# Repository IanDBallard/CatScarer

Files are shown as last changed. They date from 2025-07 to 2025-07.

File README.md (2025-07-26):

# CatScarer

An Arduino Nano-based cat deterrent system using PlatformIO for development. This device uses a PIR motion sensor to detect cats and activates deterrent mechanisms including a PWM fan, buzzer, and RGB LED indicators.

## Project Structure

```text
CatScarer/
├── src/                    # Main source code
│   ├── main.cpp           # Main Arduino sketch (CatScareDevice.ino)
│   ├── PIRSensor.h        # PIR motion sensor class header
│   ├── PIRSensor.cpp      # PIR motion sensor class implementation
│   ├── PWMFan.h           # PWM fan control class header
│   ├── PWMFan.cpp         # PWM fan control class implementation
│   ├── Buzzer.h           # Speaker control class header
│   ├── Buzzer.cpp         # Speaker control class implementation
│   ├── RGBLED.h           # RGB LED control class header
│   ├── RGBLED.cpp         # RGB LED control class implementation
│   ├── IRRemote.h         # IR remote control class header
│   ├── IRRemote.cpp       # IR remote control class implementation
│   ├── DeviceStateMachine.h    # State machine class header
│   └── DeviceStateMachine.cpp  # State machine class implementation
├── Parts/                  # 3D printable enclosure parts
│   ├── Cat Scarer Body.3mf # Main enclosure body
│   └── Cat Scarer Lid.3mf  # Enclosure lid/cover
├── include/               # Additional header files
├── lib/                   # Custom libraries
├── test/                  # Unit tests
├── .pio/                  # PlatformIO build artifacts
│   └── build/
│       └── nano/          # Arduino Nano build output
│           ├── firmware.hex    # Compiled firmware ready for upload
│           ├── firmware.elf    # Debug information
│           └── ...             # Other build files
├── platformio.ini         # PlatformIO configuration
├── .gitignore             # Git ignore rules
└── README.md              # This file
```

## 3D Printable Enclosure

### Available Parts

The project includes 3D printable enclosure parts for a complete, professional-looking cat deterrent system:

- Cat Scarer Body.3mf - Main enclosure housing for electronics
- Cat Scarer Lid.3mf - Removable lid for easy access to components

### Printing Specifications

#### Recommended Settings:

- Printer: Any FDM 3D printer (tested on Bambu Lab X1C)
- Material: PLA+ (recommended) or standard PLA
- Layer Height: 0.2mm (standard quality)
- Infill: 20-30% (adequate strength, reasonable print time)
- Supports: Required - Enable supports for overhanging features
- Bed Temperature: 60°C (PLA)
- Hotend Temperature: 210-220°C (PLA+)

#### Alternative Materials:

- PETG: More durable, higher temperature resistance
- ABS: Higher temperature resistance, requires enclosure
- TPU: Flexible, impact resistant (for outdoor use)

### Assembly Instructions

1. Print both parts using the recommended settings
2. Remove supports carefully using pliers or flush cutters
3. Clean up any stringing or remaining support material
4. Test fit the lid on the body before electronics installation
5. Install electronics into the body cavity
6. Secure lid to complete the assembly

### Enclosure Features

- Compact design - Fits all electronics components
- Ventilation holes - Proper airflow for fan operation
- Cable management - Organized routing for power and sensor cables
- Mounting options - Can be wall-mounted or placed on surface
- Weather resistance - Suitable for indoor/outdoor use (with appropriate material)

### Customization

The 3D models can be modified for:

- Different fan sizes - Adjust cavity dimensions
- Additional sensors - Add mounting points
- Different mounting - Modify base or mounting holes
- Material optimization - Adjust wall thickness for different materials

## Hardware Components

### Required Components

- Arduino Nano (ATmega328P) - Main controller
- PIR Motion Sensor - Detects cat movement
- PWM Fan - Physical deterrent (with P30N06LE MOSFET circuit)
- Buzzer - Audio deterrent (with 2N2222 transistor circuit)
- RGB LED - Status indicator (common cathode)
- Current-limiting resistors - 220Ω-330Ω for RGB LED protection

### Complete Component List

#### Microcontrollers (Choose One)

| MCU | Package | Voltage | Flash | RAM | Notes |
|-----|---|---|---|-----|---|
| Arduino Nano | DIP-28 | 5V | 32KB | 2KB | Primary Target |
| Arduino Uno | DIP-28 | 5V | 32KB | 2KB | Direct replacement |
| Arduino Pro Mini | SMD | 5V | 32KB | 2KB | Smaller footprint |
| ESP32 Dev Board | SMD | 3.3V | 4MB | 520KB | WiFi/Bluetooth |
| ESP8266 NodeMCU | SMD | 3.3V | 4MB | 80KB | WiFi enabled |
| STM32F103C8T6 | SMD | 3.3V | 64KB | 20KB | ARM Cortex-M3 |

#### Power Supply Components

| Component | Specification | Quantity | Notes |
|---|---|---|---|
| 12V Power Supply | 12V, 2A+ | 1 | For fan and buzzer |
| Buck Converter | 12V→5V, 1A+ | 1 | LM2596 or MP2307 |
| 5V Regulator | 7805 or AMS1117 | 1 | Backup 5V source |
| Capacitors | 100µF, 25V | 2 | Power filtering |
| Capacitors | 10µF, 16V | 2 | Decoupling |

#### Transistors & MOSFETs

| Component | Package | Rating | Quantity | Purpose |
|---|---|---|---|---|
| P30N06LE | TO-220 | 30A, 60V | 1 | Fan control |
| 2N2222 | TO-92 | 800mA, 40V | 1 | Buzzer control |
| TIP120 | TO-220 | 5A, 60V | 1 | Fan control (alt) |
| IRF530 | TO-220 | 14A, 100V | 1 | Fan control (alt) |

#### Diodes

| Component | Package | Rating | Quantity | Purpose |
|---|---|---|---|---|
| 1N4007 | DO-41 | 1A, 1000V | 2 | Flyback protection |
| 1N4004 | DO-41 | 1A, 400V | 2 | Flyback protection (alt) |
| 1N4001 | DO-41 | 1A, 50V | 2 | Flyback protection (alt) |

#### Resistors

| Value | Power | Quantity | Purpose |
|---|---|---|---|
| 220Ω | 1/4W | 3 | RGB LED current limiting |
| 330Ω | 1/4W | 3 | RGB LED current limiting (alt) |
| 1kΩ | 1/4W | 1 | Speaker base current limiting |
| 22Ω | 1W+ | 1 | Speaker series resistor (5V operation) |
| 10kΩ | 1/4W | 1 | MOSFET gate pull-down |
| 4.7kΩ | 1/4W | 1 | MOSFET gate pull-down (alt) |

#### Sensors & Actuators

| Component | Specification | Quantity | Notes |
|---|---|---|---|
| PIR Sensor | HC-SR501 | 1 | Motion detection |
| RGB LED | Common Cathode | 1 | Status indicator |
| PWM Fan | 12V, 120mm 4-pin PWM | 1 | Physical deterrent |
| Passive Speaker | 8Ω, 0.2W | 1 | Audio deterrent (requires 22Ω series resistor) |
| IR Receiver | TSOP1838 | 1 | Remote control input |

#### Connectors & Hardware

| Component | Specification | Quantity | Purpose |
|---|---|---|---|
| Breadboard | 830 points | 1 | Prototyping |
| Jumper Wires | Male-Male | 20 | Connections |
| Jumper Wires | Male-Female | 10 | Sensor connections |
| Power Jack | 2.1mm DC | 1 | 12V input |
| USB Cable | Type B | 1 | Programming |

### MCU Compatibility Notes

#### Arduino Nano (Primary)

- Voltage: 5V operation
- PWM Pins: 3, 5, 6, 9, 10, 11
- Digital Pins: All pins available
- Memory: Sufficient for all features

#### ESP32/ESP8266 Compatibility

- Voltage: 3.3V operation (requires level shifting)
- PWM: Software PWM on any pin
- WiFi: Built-in connectivity for remote monitoring
- Memory: Abundant for advanced features
- Pin Changes: Update pin definitions in `src/main.cpp`

#### STM32 Compatibility

- Voltage: 3.3V operation
- PWM: Hardware PWM on specific pins
- Performance: Higher clock speed, more memory
- Development: Requires STM32duino framework

### Power Supply Considerations

#### 12V Power Supply Requirements

- Minimum Current: 2A for reliable operation
- Recommended: 3A for headroom
- Voltage Stability: ±5% tolerance
- Protection: Overcurrent and short-circuit protection

#### Buck Converter Selection

- Input: 12V from power supply
- Output: 5V for Arduino, PIR Sensor, RGB LED, and Speaker (via series resistor)
- Current: 1A minimum (Arduino + sensors)
- Efficiency: 85%+ for heat management
- Popular Modules: LM2596, MP2307, XL6009

#### Power Distribution

```text
12V Power Supply
    ├── Buck Converter (12V→5V)
    │   ├── Arduino Nano (5V)
    │   ├── PIR Sensor (5V)
    │   ├── IR Receiver (5V)
    │   ├── RGB LED (5V via 220Ω resistors)
    │   └── Speaker (5V via 22Ω series resistor)
    │
    └── Fan (12V via P30N06LE MOSFET)
```

Power Requirements:

- Fan: 12V directly from power supply
- Speaker: 5V from buck converter (via 22Ω series resistor)
- Arduino & Sensors: 5V from buck converter
- RGB LED: 5V from buck converter (via current-limiting resistors)

#### Alternative Power Solutions

- USB Power: 5V directly (fan needs separate 12V)
- Battery: 12V lead-acid or LiPo with buck converter
- Solar: 12V solar panel with charge controller

### Pin Connections

| Component | Pin | Description |
|---|-----|---|
| PIR Sensor | D2 | Motion detection input |
| Fan PWM | D9 | PWM fan speed control (via P30N06LE MOSFET) |
| Speaker | D3 | Audio output control (via 2N2222 transistor) |
| RGB LED Red | D5 | Red LED control (PWM - variable brightness) |
| RGB LED Green | D6 | Green LED control (PWM - variable brightness) |
| RGB LED Blue | D8 | Blue LED control (Digital - on/off only) |
| IR Receiver | D4 | TSOP1838 IR receiver for remote control |

## Hardware Circuit Diagrams

### Power Distribution Circuit

```text
12V Power Supply (+) ── Buck Converter Input (+)
12V Power Supply (-) ── Buck Converter Input (-) ── GND
Buck Converter Output (+) ── Arduino 5V Pin
Buck Converter Output (-) ── Arduino GND Pin ── GND
```

### Fan Control Circuit (P30N06LE MOSFET)

```text
12V Power Supply (+) ── Fan (Pin 2: +12V Power, Yellow/Red wire)
Fan (Pin 1: Ground, Black wire) ── P30N06LE Drain (Pin 2)
P30N06LE Source (Pin 3) ── GND
Arduino D9 ── P30N06LE Gate (Pin 1) ── 10kΩ Resistor ── GND
                                            (Pull-down resistor for gate)
Flyback Diode (1N4007) across Fan: Cathode to Fan(+), Anode to Fan(-)
```

Fan Wire Colors (4-pin PWM):

- Black: Ground (Pin 1)
- Yellow/Red: +12V Power (Pin 2)
- Blue: PWM Control (Pin 3) - Not used in this circuit
- Green/Yellow: Sense (Pin 4) - Not used in this circuit

### Speaker Circuit (2N2222 Transistor)

```text
Buck Converter 5V Output (+) ── 22Ω Series Resistor (1W+) ── Speaker (+)
Speaker (-) ── 2N2222 Collector
2N2222 Emitter ── GND
Arduino D3 ── 1kΩ Resistor ── 2N2222 Base
Flyback Diode (1N4007) across Speaker: Cathode to Speaker(+), Anode to Speaker(-)
```

Important Notes:

- 5V Power: Supplied by buck converter, not direct Arduino 5V
- Series Resistor: 22Ω, 1W+ required to limit current for 8Ω speaker
- Transistor: 2N2222 switches speaker to ground when Arduino pin is HIGH

### RGB LED Circuit

```text
Buck Converter 5V Output (+) ── 220Ω Resistor ── RGB LED Red Anode
Buck Converter 5V Output (+) ── 220Ω Resistor ── RGB LED Green Anode
Buck Converter 5V Output (+) ── 220Ω Resistor ── RGB LED Blue Anode
RGB LED Common Cathode ── GND
Arduino D5 ── RGB LED Red Anode (via 220Ω resistor)
Arduino D6 ── RGB LED Green Anode (via 220Ω resistor)
Arduino D8 ── RGB LED Blue Anode (via 220Ω resistor)
```

### PIR Sensor Circuit

```text
Buck Converter 5V Output (+) ── PIR Sensor VCC
PIR Sensor GND ── GND
PIR Sensor OUT ── Arduino D2
```

### IR Receiver Circuit

```text
Buck Converter 5V Output (+) ── IR Receiver VCC
IR Receiver GND ── GND
IR Receiver OUT ── Arduino D4
```

### Complete Wiring Diagram

```text
12V Power Supply
    │
    ├── Buck Converter (12V→5V)
    │   ├── Arduino Nano (5V, GND)
    │   ├── PIR Sensor (5V, GND, D2)
    │   ├── IR Receiver (5V, GND, D4)
    │   ├── RGB LED (5V via 220Ω resistors, D5/D6/D8)
    │   └── Speaker Circuit (5V via 22Ω resistor, D3)
    │
    └── Fan Circuit (12V, D9)
        └── P30N06LE MOSFET (D9 → Gate, Fan → Drain, Source → GND)
```

Ground Connections:

- All GND connections must be connected to a single common ground rail
- Buck converter output GND connects to Arduino GND
- All component GND connections connect to this common ground

## Features

### Motion Detection

- PIR sensor continuously monitors for movement
- 45-second warm-up period to establish baseline readings
- Configurable sensitivity and detection range
- Encapsulated warm-up logic within PIRSensor class

### Deterrent Mechanisms

- PWM Fan: Variable speed control for physical deterrent
- Buzzer: Audio deterrent with transistor amplification and siren mode
- RGB LED: Visual status indication
  - Blue flickering: PIR sensor warming up
  - Green solid: Ready/Standby mode
  - Red solid: Active deterrent mode
  - Yellow solid: Inactive mode (device disabled)

### Behavior

- Initialization: 45-second PIR warm-up with blue LED flickering
- Activation: Triggers when motion is detected (after warm-up)
- Duration: Configurable activation time (default: 5 seconds)
- Auto-reset: Returns to standby after activation period
- Continuous monitoring: Refreshes timer if motion continues
- Remote Control: IR remote power toggle to enter/exit inactive mode
- Inactive Mode: Device ignores PIR input when disabled via remote

### Remote Control Operation

The device supports IR remote control using a TSOP1838 receiver and Elegoo-compatible remote:

- Power Toggle: Press power button to toggle between active and inactive modes
- State Transitions: Power toggle works from any state (WARMUP, STANDBY, ACTIVE)
- Inactive Mode: When inactive, device ignores all PIR motion detection
- Visual Feedback: Yellow LED indicates inactive state
- Testing: Send 'P' via serial monitor to simulate power toggle during development

### State Logic

The device operates using a state machine with four distinct states:

```mermaid
WARMUP → STANDBY → ACTIVE
   ↑         ↑         ↑
   └─────────┴─────────┘
        Power Toggle
           ↓
        INACTIVE
           ↑
        Power Toggle
```

- WARMUP: PIR sensor initializing (45 seconds), blue LED flickers
- STANDBY: Ready for motion detection, green LED solid
- ACTIVE: Deterrent active, red LED solid, fan and buzzer running
- INACTIVE: Device disabled, yellow LED solid, ignores PIR input

## Setup

### Prerequisites

1. Install [PlatformIO Core](https://platformio.org/install/cli)
2. Install [Git](https://git-scm.com/)

### Installation

1. Clone this repository:

   ```bash
   git clone <your-repo-url>
   cd CatScarer
   ```

2. Install dependencies:

   ```bash
   pio lib install
   ```

## Usage

### Building

Build for Arduino Nano (default):

```bash
pio run
```

Build for Arduino Nano (explicit):

```bash
pio run -e nano
```

Build for other boards:

```bash
pio run -e uno
pio run -e esp32dev
```

### Uploading

Upload to Arduino Nano (default):

```bash
pio run -t upload
```

Upload to Arduino Nano (explicit):

```bash
pio run -e nano -t upload
```

### Monitoring

Monitor serial output for debugging:

```bash
pio device monitor
```

### Testing

Run all tests:

```bash
pio test
```

## Configuration

### Behavior Parameters

Edit `src/main.cpp` to customize:

```cpp
// Device behavior parameters
const unsigned long ACTIVATION_DURATION_MS = 5000; // Activation duration in milliseconds
const int FAN_SPEED_ACTIVATED = 255; // Fan speed when activated (0-255)

// State machine enum (for reference)
enum DeviceState {
    WARMUP,    // PIR sensor is warming up
    STANDBY,   // Ready for motion detection
    ACTIVE,    // Deterrent is active
    INACTIVE   // Device disabled, ignoring PIR input
};
```

### PIR Sensor Configuration

Edit `src/PIRSensor.cpp` to customize warm-up time:

```cpp
// In constructor - change warm-up duration (default: 45 seconds)
_warmUpDuration(45000) // 45 seconds in milliseconds

// The PIRSensor class includes an update() method that should be called
// in the main loop() for proper state management
```

### Pin Assignments

Modify pin definitions in `src/main.cpp`:

```cpp
const int PIR_PIN = 2;        // PIR sensor pin
const int FAN_PWM_PIN = 9;    // Fan PWM control pin
const int BUZZER_PIN = 3;     // Buzzer control pin
const int LED_RED_PIN = 5;    // RGB LED red pin (PWM)
const int LED_GREEN_PIN = 6;  // RGB LED green pin (PWM)
const int LED_BLUE_PIN = 8;   // RGB LED blue pin (Digital only)
const int IR_RECEIVER_PIN = 4; // IR receiver pin
```

## Hardware Circuit

### Fan Control Circuit Details (P30N06LE MOSFET)

```text
Arduino D9 ──┬── 10kΩ Resistor ── GND
            │
            └── P30N06LE Gate
                    ↓
                P30N06LE Source ── GND
                    ↓
                P30N06LE Drain ── Fan (+)
                          ↓
                      Fan (-) ── GND
                          │
                      Flyback Diode (1N4007)
```

Component Details:

- P30N06LE: N-channel MOSFET (30A, 60V)
- 10kΩ Resistor: Pull-down resistor for gate
- Fan: 12V or 5V PC fan (4-pin PWM fan supported)
- 1N4007 Diode: Flyback protection diode (cathode to fan +, anode to fan -)

### Buzzer Circuit (2N2222 Transistor)

```text
Arduino D3 ──┬── 1kΩ Resistor ── 2N2222 Base
            │
            └── 2N2222 Emitter ── GND
                    ↓
                2N2222 Collector ── Buzzer (+)
                          ↓
                      Buzzer (-) ── GND
                          │
                      Flyback Diode (1N4007)
```

Component Details:

- 2N2222: NPN transistor for current amplification
- 1kΩ Resistor: Base current limiting resistor
- Buzzer: 5V or 12V piezo buzzer
- 1N4007 Diode: Flyback protection diode (cathode to buzzer +, anode to buzzer -)

### RGB LED Circuit (Common Cathode)

```text
Arduino D5 ── 220Ω Resistor ── LED Red Anode (PWM - variable brightness)
Arduino D6 ── 220Ω Resistor ── LED Green Anode (PWM - variable brightness)
Arduino D8 ── 220Ω Resistor ── LED Blue Anode (Digital - on/off only)
Arduino D4 ── TSOP1838 IR Receiver (Signal)
TSOP1838 VCC ── 5V
TSOP1838 GND ── GND
                    │
                LED Common Cathode ── GND
```

Component Details:

- 220Ω Resistors: Current-limiting resistors (220Ω-330Ω acceptable)
- RGB LED: Common cathode type (longest pin = cathode)
- Pin Configuration: Red, Green, Blue anodes + Common cathode
- PWM Control: Red and Green channels support variable brightness (0-255)
- Digital Control: Blue channel is on/off only due to non-PWM pin limitation

### Complete Wiring Diagram

```text
Arduino Nano
┌─────────────────────────────────────────────────────────┐
│                                                         │
│  D2 ────────────────── PIR Sensor OUT                   │
│                                                         │
│  D3 ── 1kΩ ── 2N2222 Base                              │
│             2N2222 Emitter ── GND                       │
│             2N2222 Collector ── Buzzer (+)              │
│                                    Buzzer (-) ── GND    │
│                                    │                    │
│                                    └─ 1N4007 Diode ─────┘
│                                                         │
│  D5 ── 220Ω ── RGB LED Red Anode                        │
│  D6 ── 220Ω ── RGB LED Green Anode                      │
│  D8 ── 220Ω ── RGB LED Blue Anode                       │
│                                    RGB LED Cathode ── GND│
│                                                         │
│  D9 ── 10kΩ ── P30N06LE Gate                            │
│              P30N06LE Source ── GND                     │
│              P30N06LE Drain ── Fan (+)                  │
│                                    Fan (-) ── GND       │
│                                    │                    │
│                                    └─ 1N4007 Diode ─────┘
│                                                         │
│  VIN ── 12V Power Supply (for fan)                      │
│  5V ── 5V Power Supply (for Arduino)                    │
│  GND ── Common Ground                                   │
└─────────────────────────────────────────────────────────┘
```

### Power Supply Requirements

- Arduino Nano: 5V via USB or VIN pin
- Fan: 12V (or 5V depending on fan type)
- Buzzer: 5V or 12V (check buzzer specifications)
- RGB LED: 5V (regulated by resistors)
- PIR Sensor: 5V

### Component Specifications

| Component | Specification | Notes |
|---|---|---|
| P30N06LE | 30A, 60V N-MOSFET | TO-220 package |
| 2N2222 | 800mA, 40V NPN | TO-92 package |
| RGB LED | Common Cathode | 20mA per color |
| Resistors | 220Ω-330Ω | 1/4W or higher |
| Fan | 12V PWM | 4-pin connector supported |
| Buzzer | 5V/12V Piezo | Check voltage rating |
| 1N4007 | 1A, 1000V Diode | Flyback protection (2x) |

## Supported Boards

- Arduino Nano (Primary target - ATmega328P)
- Arduino Uno
- ESP32 Dev Board
- ESP8266 NodeMCU

## Development

### Adding Libraries

Add libraries to `platformio.ini`:

```ini
lib_deps =
    library_name
    another_library
```

Or install via command line:

```bash
pio lib install "library_name"
```

### Software Architecture

The project follows object-oriented design principles with proper encapsulation and separation of concerns:

#### Component Classes

- `PIRSensor`: Motion detection interface with built-in warm-up logic and state management
- `PWMFan`: Fan speed control with PWM support
- `Buzzer`: Audio output control with non-blocking siren mode
- `RGBLED`: Color LED control with PWM support for red/green channels
- `IRRemote`: IR remote control interface with debouncing and power toggle support

#### State Management

- `DeviceStateMachine`: Centralized state machine managing device behavior and transitions
  - WARMUP: PIR sensor initialization (45 seconds)
  - STANDBY: Ready for motion detection
  - ACTIVE: Deterrents active
  - INACTIVE: Device disabled via remote control

#### Main Program Structure

```cpp
void loop() {
  // Update all component states
  myPIR.update();
  myBuzzer.update();
  myIRRemote.update();

  // Update state machine
  stateMachine.update();
}
```

#### Design Benefits

- Encapsulation: Each class has clear responsibilities
- Maintainability: Changes to state logic only affect DeviceStateMachine
- Testability: Individual classes can be unit tested
- Reusability: Methods can be used by other parts of the code
- No Global State: All state is properly encapsulated

#### Recent Refactoring Improvements (V1.4.2)

- Eliminated Stranded Methods: Moved `checkIRPowerToggle()` to `IRRemote` class
- State Machine Encapsulation: Created `DeviceStateMachine` class for all state logic
- Cleaner Main Loop: Simplified main.cpp to focus on orchestration
- Better Code Organization: Proper separation of concerns
- Enhanced Maintainability: Easier to modify and extend functionality

### Project Configuration

Edit `platformio.ini` to customize:

- Board settings
- Build flags
- Upload settings
- Monitor configuration

## Troubleshooting

### Common Issues

1. Upload fails: Check USB connection and COM port
2. PIR not detecting: Verify wiring and wait for 45-second warm-up
3. Fan not spinning: Check MOSFET circuit and PWM pin
4. Buzzer not working: Verify transistor circuit and pin connections
5. LED dim or wrong colors: Check resistor values (should be 220Ω-330Ω)

### LED Status Indicators

- Blue flickering: PIR sensor warming up (45 seconds)
- Green solid: Ready for motion detection (STANDBY state)
- Red solid: Motion detected, deterrents active (ACTIVE state)
- Yellow solid: Device disabled via remote control (INACTIVE state)

### Debug Output

Enable serial monitoring to see debug messages:

```bash
pio device monitor
```

Expected output:

```text
Cat Scare Device Starting...
Testing LED colors...
Testing RED pin (D5)...
Testing GREEN pin (D6)...
Testing BLUE pin (D8)...
ALL LEDS OFF
PIR sensor warming up...
Device ready.
Device State Machine initialized.
Warm-up complete. Entering standby mode.
Motion detected! Activating deterrent...
Setting LED to RED (255,0,0)
Deactivating deterrent...
Setting LED to GREEN (0,255,0)
IR Power toggle: Entering inactive mode.
IR Power toggle: Exiting inactive mode, entering standby.
```

## Contributing

1. Fork the repository
2. Create a feature branch
3. Make your changes
4. Add tests if applicable
5. Submit a pull request

## License

This project is licensed under the GNU General Public License v3.0 - see the [LICENSE](LICENSE) file for details.

### License Summary

- License: GNU General Public License v3.0
- Permissions: Commercial use, modification, distribution, patent use, private use
- Conditions: License and copyright notice must be included, state changes must be disclosed, source code must be made available
- Limitations: No warranty, no liability

For more information about the GPL v3 license, visit: https://www.gnu.org/licenses/gpl-3.0.html

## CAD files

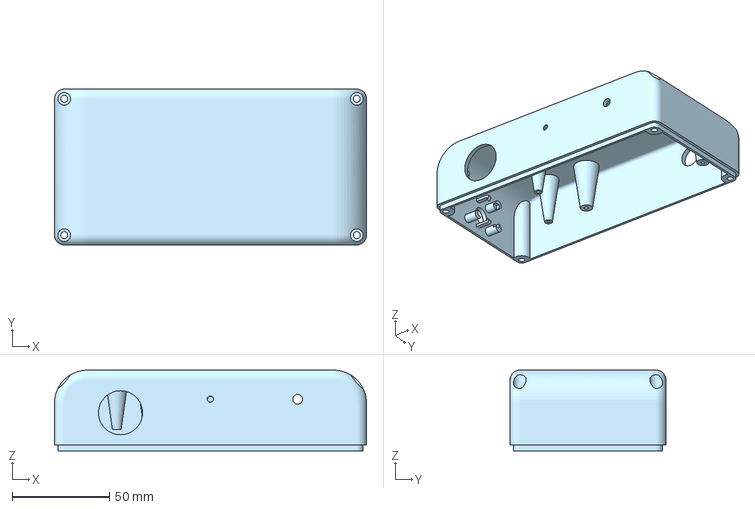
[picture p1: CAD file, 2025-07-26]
Parts/Cat Scarer Lid with IR Receiver.3mf
160.2 x 80.0 x 41.5 mm

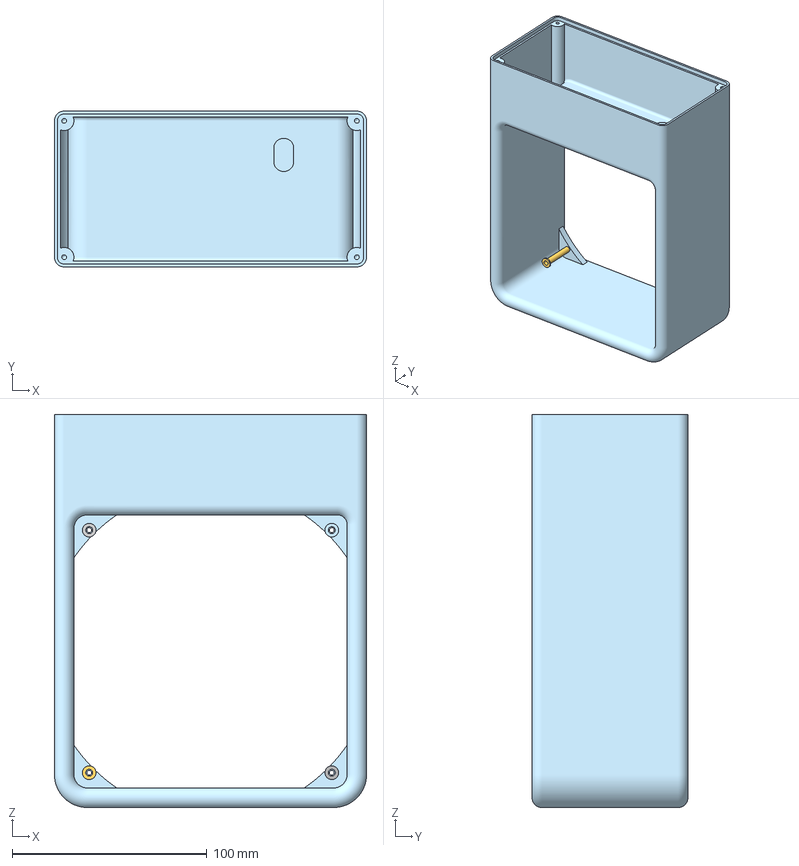
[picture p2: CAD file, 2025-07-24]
Parts/Cat Scarer Body.3mf
160.2 x 80.0 x 201.7 mm

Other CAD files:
Parts/Cat Scarer Lid.3mf

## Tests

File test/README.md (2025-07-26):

# CatScarer Test Suite

This directory contains comprehensive Unity test suites for all CatScarer classes to ensure code quality and reliability.

## Test Coverage

### PIRSensor Tests (`test_PIRSensor.cpp`)

- ✅ Constructor and pin assignment
- ✅ Initialization and warm-up period (45 seconds)
- ✅ Motion detection during and after warm-up
- ✅ State management and transitions
- ✅ Pin getter functionality

### Buzzer Tests (`test_Buzzer.cpp`)

- ✅ Constructor and pin assignment
- ✅ Basic turnOn/turnOff functionality
- ✅ Siren mode activation and deactivation
- ✅ Non-blocking tone switching (800Hz ↔ 400Hz)
- ✅ Timing and duration management
- ✅ State tracking and queries

### IRRemote Tests (`test_IRRemote.cpp`)

- ✅ Constructor and pin assignment
- ✅ IR signal detection and command parsing
- ✅ Power toggle functionality
- ✅ Debouncing (200ms delay)
- ✅ Serial simulation for testing
- ✅ State management and clearing

### DeviceStateMachine Tests (`test_DeviceStateMachine.cpp`)

- ✅ Constructor and initialization
- ✅ All state transitions (WARMUP → STANDBY → ACTIVE → INACTIVE)
- ✅ IR power toggle integration
- ✅ Motion detection integration
- ✅ Duration management and timeouts
- ✅ Component coordination (LED, Fan, Buzzer)
- ✅ State name resolution

## Running Tests

### Run All Tests

```bash
pio test -e native
```

### Run Individual Test Suites

```bash
# PIRSensor tests only
pio test -e native -f test_PIRSensor

# Buzzer tests only
pio test -e native -f test_Buzzer

# IRRemote tests only
pio test -e native -f test_IRRemote

# DeviceStateMachine tests only
pio test -e native -f test_DeviceStateMachine
```

### Run Specific Test Functions

```bash
# Run specific test function
pio test -e native -f test_PIRSensor_constructor
pio test -e native -f test_Buzzer_siren_update_tone_switching
pio test -e native -f test_DeviceStateMachine_standby_to_active
```

## Test Architecture

### Mock System

- **Arduino Functions**: Mocked `millis()`, `tone()`, `noTone()`, `Serial`
- **Hardware Abstraction**: Mock classes for all components
- **Time Control**: Controlled timing for testing time-based behavior

### Test Fixtures

Each test suite includes:

- `setUp()`: Initialize test objects and reset mocks
- `tearDown()`: Clean up allocated memory
- Mock objects for isolated testing

### Mock Classes

- `MockPIRSensor`: Simulates PIR sensor behavior
- `MockPWMFan`: Tracks fan state and speed
- `MockBuzzer`: Simulates buzzer and siren behavior
- `MockRGBLED`: Captures LED color commands
- `MockIRRemote`: Simulates IR remote interactions

## Test Categories

### Unit Tests

- Individual method functionality
- Constructor and initialization
- State management
- Error handling

### Integration Tests

- Component interaction
- State machine transitions
- Timing and coordination
- End-to-end workflows

### Behavioral Tests

- Real-world scenarios
- Edge cases and timing
- State transitions
- User interactions

## Expected Test Results

### All Tests Should Pass

```bash
=== Running PIRSensor Tests ===
test_PIRSensor_constructor:PASS
test_PIRSensor_begin:PASS
test_PIRSensor_warmup_period:PASS
...

=== Running Buzzer Tests ===
test_Buzzer_constructor:PASS
test_Buzzer_startSiren:PASS
test_Buzzer_siren_update_tone_switching:PASS
...

=== Running IRRemote Tests ===
test_IRRemote_constructor:PASS
test_IRRemote_update_power_command:PASS
test_IRRemote_debouncing:PASS
...

=== Running DeviceStateMachine Tests ===
test_DeviceStateMachine_constructor:PASS
test_DeviceStateMachine_standby_to_active:PASS
test_DeviceStateMachine_active_duration:PASS
...

=== All Tests Complete ===
```

## Adding New Tests

### For New Classes

1. Create `test_ClassName.cpp`
2. Include Unity and class header
3. Add mock functions as needed
4. Create test functions with descriptive names
5. Add to `run_all_tests.cpp`

### For New Methods

1. Add test function to existing test file
2. Test normal operation
3. Test edge cases
4. Test error conditions
5. Update test runner

### Test Naming Convention

- `test_ClassName_methodName_behavior()`
- `test_ClassName_methodName_edgeCase()`
- `test_ClassName_methodName_errorCondition()`

## Continuous Integration

These tests can be integrated into CI/CD pipelines to:
- ✅ Ensure code quality
- ✅ Prevent regressions
- ✅ Validate refactoring
- ✅ Document expected behavior
- ✅ Enable safe development

## Troubleshooting

### Test Failures

1. Check mock setup in `setUp()`
2. Verify timing in time-based tests
3. Ensure proper state initialization
4. Check for memory leaks in `tearDown()`

### Compilation Issues

1. Verify Unity library is installed
2. Check include paths
3. Ensure mock functions are defined
4. Validate C++ standard compatibility

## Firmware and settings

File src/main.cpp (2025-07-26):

// CatScareDevice.ino

// Include our custom classes
#include "PIRSensor.h"
#include "PWMFan.h"
#include "Buzzer.h"
#include "RGBLED.h"
#include "IRRemote.h"
#include "DeviceStateMachine.h"

// --- Pin Definitions ---
// Connect PIR Sensor OUT pin to this digital input pin
const int PIR_PIN = 2; // Using D2 for PIR sensor

// Connect Fan PWM input wire (usually yellow) to this PWM pin
// The fan's power is controlled by the TIP120 transistor circuit.
const int FAN_PWM_PIN = 9; // Using D9 for PWM fan control (must be a PWM pin)

// Connect Buzzer signal pin (via 2N2222 transistor circuit) to this digital output pin
const int BUZZER_PIN = 3; // Using D3 for buzzer control

// RGB LED Pins (connect via current-limiting resistors)
// Red and Green pins are PWM-capable for variable brightness
// Blue pin is digital only (on/off)
const int LED_RED_PIN   = 5; // Using D5 for Red LED (PWM)
const int LED_GREEN_PIN = 6; // Using D6 for Green LED (PWM)
const int LED_BLUE_PIN  = 8; // Using D8 for Blue LED (digital only)

// IR Receiver Pin (TSOP1838)
const int IR_RECEIVER_PIN = 4; // Using D4 for IR receiver

// --- Device Behavior Parameters ---
const unsigned long ACTIVATION_DURATION_MS = 5000; // How long the fan/buzzer stays on (5 seconds)
const int FAN_SPEED_ACTIVATED = 255; // Fan speed when activated (0-255, 255 is full speed)

// --- Object Instantiation ---
// Create instances of our component classes
PIRSensor myPIR(PIR_PIN);
PWMFan myFan(FAN_PWM_PIN);
Buzzer myBuzzer(BUZZER_PIN);
RGBLED myLED(LED_RED_PIN, LED_GREEN_PIN, LED_BLUE_PIN);
IRRemote myIRRemote(IR_RECEIVER_PIN);

// Create state machine instance
DeviceStateMachine stateMachine(myPIR, myFan, myBuzzer, myLED, myIRRemote, 
                                ACTIVATION_DURATION_MS, FAN_SPEED_ACTIVATED);

void setup() {
  // Initialize Serial communication for debugging
  Serial.begin(9600);
  Serial.println("Cat Scare Device Starting...");

  // Initialize all components
  myPIR.begin();
  myFan.begin();
  myBuzzer.begin();
  myLED.begin();
  myIRRemote.begin();
  stateMachine.begin();

  // LED Test - cycle through colors
  Serial.println("Testing LED colors...");
  Serial.println("NOTE: If LED is dim, check resistor value (should be 220-330Ω)");
  
  // Test each pin individually to identify connections
  Serial.println("Testing RED pin (D5)...");
  myLED.setColor(255, 0, 0); // Red ON, others OFF
  delay(3000);
  
  Serial.println("Testing GREEN pin (D6)...");
  myLED.setColor(0, 255, 0); // Green ON, others OFF
  delay(3000);
  
  Serial.println("Testing BLUE pin (D8)...");
  myLED.setColor(0, 0, 255); // Blue ON, others OFF
  delay(3000);
  
  // Test all off
  myLED.setColor(0, 0, 0); // All OFF
  Serial.println("ALL LEDS OFF");
  delay(2000);

  Serial.println("PIR sensor warming up...");
  Serial.println("Device ready.");
}

void loop() {
  // Update all component states
  myPIR.update();
  myBuzzer.update();
  myIRRemote.update();
  
  // Update state machine
  stateMachine.update();
}

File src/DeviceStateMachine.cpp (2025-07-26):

#include "DeviceStateMachine.h"

// Constructor implementation
DeviceStateMachine::DeviceStateMachine(PIRSensor& pirSensor, PWMFan& pwmFan, Buzzer& buzzerObj, 
                                       RGBLED& rgbLed, IRRemote& irRemote, 
                                       unsigned long durationMs, int fanSpeed)
    : pir(pirSensor), fan(pwmFan), buzzer(buzzerObj), led(rgbLed), ir(irRemote),
      currentState(WARMUP), activationStartTime(0), lastFlicker(0), ledState(false),
      activationDurationMs(durationMs), fanSpeedActivated(fanSpeed) {
}

// begin() method implementation
void DeviceStateMachine::begin() {
    currentState = WARMUP;
    activationStartTime = 0;
    lastFlicker = 0;
    ledState = false;
    Serial.println("Device State Machine initialized.");
}

// update() method implementation
void DeviceStateMachine::update() {
    // State machine logic
    switch (currentState) {
        case WARMUP:
            handleWarmupState();
            break;
            
        case STANDBY:
            handleStandbyState();
            break;
            
        case ACTIVE:
            handleActiveState();
            break;
            
        case INACTIVE:
            handleInactiveState();
            break;
    }
}

// handleWarmupState() method implementation
void DeviceStateMachine::handleWarmupState() {
    // Check for IR power toggle (can interrupt warm-up)
    if (ir.checkPowerToggle()) {
        currentState = INACTIVE;
        Serial.println("IR Power toggle: Entering inactive mode.");
        return;
    }
    
    // Flicker blue LED during warm-up
    if (millis() - lastFlicker >= 500) { // Flicker every 500ms
        ledState = !ledState;
        led.setColor(0, 0, ledState ? 255 : 0); // Blue on/off
        lastFlicker = millis();
    }
    
    // Check if warm-up is complete
    if (!pir.isInitializing()) {
        currentState = STANDBY;
        Serial.println("Warm-up complete. Entering standby mode.");
    }
}

// handleStandbyState() method implementation
void DeviceStateMachine::handleStandbyState() {
    // Check for IR power toggle
    if (ir.checkPowerToggle()) {
        currentState = INACTIVE;
        Serial.println("IR Power toggle: Entering inactive mode.");
        return;
    }
    
    // Show green LED to indicate ready state
    led.setColor(0, 255, 0); // Green = ready
    
    // Check for motion detection
    if (pir.isMotionDetected()) {
        // Transition to active state
        currentState = ACTIVE;
        activationStartTime = millis();
        
        Serial.println("Motion detected! Activating deterrent...");
        Serial.println("Setting LED to RED (255,0,0)");
        led.setColor(255, 0, 0); // Red
        fan.turnOn(fanSpeedActivated);
        buzzer.startSiren();
    }
}

// handleActiveState() method implementation
void DeviceStateMachine::handleActiveState() {
    // Check for IR power toggle (can interrupt active state)
    if (ir.checkPowerToggle()) {
        currentState = INACTIVE;
        Serial.println("IR Power toggle: Entering inactive mode.");
        // Stop deterrent immediately
        fan.turnOff();
        buzzer.stopSiren();
        return;
    }
    
    // Check if motion is still detected (refresh timer)
    if (pir.isMotionDetected()) {
        activationStartTime = millis(); // Refresh the timer
    }
    
    // Check if activation duration has expired
    if (millis() - activationStartTime >= activationDurationMs) {
        // Transition back to standby
        currentState = STANDBY;
        
        Serial.println("Deactivating deterrent...");
        Serial.println("Setting LED to GREEN (0,255,0)");
        led.setColor(0, 255, 0); // Green
        fan.turnOff();
        buzzer.stopSiren();
    }
}

// handleInactiveState() method implementation
void DeviceStateMachine::handleInactiveState() {
    // Check for IR power toggle to exit inactive state
    if (ir.checkPowerToggle()) {
        currentState = STANDBY;
        Serial.println("IR Power toggle: Exiting inactive mode, entering standby.");
        return;
    }
    
    // Show yellow LED to indicate inactive state (red + green)
    led.setColor(255, 255, 0); // Yellow = inactive
    
    // In inactive state, ignore all PIR motion detection
    // No deterrent activation occurs
}

// getCurrentState() method implementation
DeviceState DeviceStateMachine::getCurrentState() const {
    return currentState;
}

// setState() method implementation
void DeviceStateMachine::setState(DeviceState newState) {
    currentState = newState;
    Serial.print("State changed to: ");
    Serial.println(getStateName());
}

// getStateName() method implementation
const char* DeviceStateMachine::getStateName() const {
    switch (currentState) {
        case WARMUP: return "WARMUP";
        case STANDBY: return "STANDBY";
        case ACTIVE: return "ACTIVE";
        case INACTIVE: return "INACTIVE";
        default: return "UNKNOWN";
    }
} 

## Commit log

2025-07-24 Add 3D printed parts - Cat Scarer Body and Lid
    [Cat Scarer Body.3mf, Cat Scarer Lid.3mf]
2025-07-25 feat: Major code improvements and GPL v3 license
    - Add GPL v3 license to project
    - Refactor main.cpp to use state machine (WARMUP/STANDBY/ACTIVE)
    - Add PIRSensor update() method for better state management
    - Implement true PWM control for RGB LED (red/green channels)
    - Remove blocking delays for improved responsiveness
    - Update documentation with state logic and PWM details
    - Fix function declaration issues
    - All code compiles successfully for all target boards
    [RGBLED.cpp, main.cpp]
2025-07-25 feat: Add INACTIVE state with IR remote control
    - Add INACTIVE state to state machine (yellow LED)
    - Implement IRRemote class for TSOP1838 receiver
    - Add power toggle functionality from any state
    - Support Elegoo remote control compatibility
    - Add serial testing mode ('P' command)
    - Update documentation with IR control details
    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
2025-07-26 V1.4.1: Critical hardware documentation corrections and circuit diagrams
2025-07-26 V1.4.2: Refactor stranded methods into proper classes - improve code organization
    [Cat Scarer Lid with IR Receiver.3mf]
2025-07-27 V1.4.8: Clean up test framework and restore to stable state
